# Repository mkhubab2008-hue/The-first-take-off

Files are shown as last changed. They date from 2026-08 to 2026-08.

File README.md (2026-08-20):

## 🎥 Demo
Watch The first take off :
## Overview
I wanted to make small esp32c3 based qaudcopter that I could control from my Phone. I first tried to use WiFi, but the WiFi chip on my ESP wouldnt seem to work. So, I switched to BLE. The drone uses an MPU6050 as its Gyroscope.
## How it works
The Gyroscope measures the rate of change of angles and the desired rates of roll pitch and yaw are sent over BLE from an android app that I made using MIT app maker. The micro-controller measures the difference between the desired rates and the current rates then uses a PID loop to calculate the motor input required at each motor to correct the rotation rates in each axis. The loop has a frequency of 250hz so fresh commands are sent to the motor every 4 milliseconds.
## Bill of Materials (BOM)

| Component | Description | Qty | Price (USD) | Link |
| :--- | :--- | :--- | :--- | :--- |
| **Microcontroller** | ESP32-C3 Super Mini Development Board | 1 | $2.21 | [AliExpress](https://www.aliexpress.com/w/wholesale-esp32-c3-super-mini.html) |
| **IMU Sensor** | GY-521 MPU-6050 6-DOF Accelerometer/Gyroscope | 1 | $1.59 | [AliExpress](https://www.aliexpress.com/w/wholesale-gy-521-mpu6050.html) |
| **Motors & Props** | 8520 Coreless Brushed DC Motors (CW/CCW) with Propellers | 4 | $5.81 | [AliExpress](https://www.aliexpress.com/w/wholesale-coreless-motor-8520-propeller.html) |
| **Motor Drivers** | SI2300 N-Channel MOSFETs (SOT-23 package) | 50 | $0.99 | [AliExpress](https://www.aliexpress.com/w/wholesale-si2300.html) |
| **Flyback Diodes** | 1N4148 Switching Diodes (SMD 1206) | 50 | $0.61 | [AliExpress](https://www.aliexpress.com/w/wholesale-switching-diode-1n4148.html) |
| **Gate Resistors** | 200Ω Resistors (PWM current limiting) | 100 | $0.99 | [AliExpress](https://www.aliexpress.com/w/wholesale-200-ohm-1-watt-resistor.html) |
| **Pull-down Resistors** | 10kΩ Resistors | 100 | $0.99 | [AliExpress](https://www.aliexpress.com/w/wholesale-10k-pull-up-resistor.html) |
| **Bulk Capacitor** | 470µF 16V/25V Electrolytic Capacitor (Main battery filtering) | 4 | $1.51 | [AliExpress](https://www.aliexpress.com/w/wholesale-470uf-capacitor.html) |
| **Capacitors** | 100µF & 10µF Assortment (Decoupling/Filtering) | 1 kit | $1.50 | [AliExpress](https://www.aliexpress.com/w/wholesale-smd-capacitor-assortment.html) |
| **Voltage Regulator** | XC6206P332MR 3.3V LDO Voltage Regulator (SOT-23) | 20 | $1.91 | [AliExpress](https://www.aliexpress.com/item/32811070407.html) |
| **Prototyping Board** | Double-sided Perfboard (2x8cm) | 10 | $1.20 | [AliExpress](https://www.aliexpress.com/w/wholesale-double-sided-perfboard.html) |
| **Wiring** | 30AWG Flexible Silicone Wire Kit | 1 kit | $3.50 | [AliExpress](https://www.aliexpress.com/w/wholesale-30awg-silicone-wire-kit.html) |
| **Battery** | 1S 3.7V 500mAh LiPo Battery | 1 | $7.00 | [AliExpress](https://www.aliexpress.com/item/1005003268560510.html) |
| **Airframe** | 3D Printed Frame Service (SLA/Resin) | 1 | $1.00 | [JLCPCB](https://jlcpcb.com/3d-printing) |
| **Total** | | | **$30.81** | |

## Wiring diagram
WhatsApp Image 2026-08-20 at 5 38 04 PM

## Programming
*Software required*:-
1) Arduino IDE
2) ESP32C3 libaries
3) MPU6050 library
4) BLE libraries

*Customizing the P, I and D gains*:-

In my opinion the only method for obtaining the right gains is just trial error; because everydrone, even if it foollows the same blueprint, will have a different COM and mass. The following guide can be quite helpful in determining the gains:-
WhatsApp Image 2026-08-20 at 11 23 37 AM
Furthermore, I think it is also prudent to add the ability to change the PID gains wirelessly as plugging the drone in repeatedly can be quite annoying. I did this by adding a BLE characteristic to wirelessly send the commands from my phone using nrf connect.

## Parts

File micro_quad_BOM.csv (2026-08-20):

Component | Description | Qty | Price (USD) | Link
Microcontroller | ESP32-C3 Super Mini Development Board | 1 | 2.21 | https://www.aliexpress.com/w/wholesale-esp32-c3-super-mini.html
IMU Sensor | GY-521 MPU-6050 6-DOF Accelerometer/Gyroscope | 1 | 1.59 | https://www.aliexpress.com/w/wholesale-gy-521-mpu6050.html
Motors & Props | 8520 Coreless Brushed DC Motors (CW/CCW) with Propellers | 4 | 5.81 | https://www.aliexpress.com/w/wholesale-coreless-motor-8520-propeller.html
Motor Drivers | SI2300 N-Channel MOSFETs (SOT-23 package) | 50 | 0.99 | https://www.aliexpress.com/w/wholesale-si2300.html
Flyback Diodes | 1N4148 Switching Diodes (SMD 1206) | 50 | 0.61 | https://www.aliexpress.com/w/wholesale-switching-diode-1n4148.html
Gate Resistors | 200Ω Resistors (PWM current limiting) | 100 | 0.99 | https://www.aliexpress.com/w/wholesale-200-ohm-1-watt-resistor.html
Pull-down Resistors | 10kΩ Resistors | 100 | 0.99 | https://www.aliexpress.com/w/wholesale-10k-pull-up-resistor.html
Bulk Capacitor | 470µF 16V/25V Electrolytic Capacitor (Main battery filtering) | 4 | 1.51 | https://www.aliexpress.com/w/wholesale-470uf-capacitor.html
Capacitors | 100µF & 10µF Assortment (Decoupling/Filtering) | 1 kit | 1.50 | https://www.aliexpress.com/w/wholesale-smd-capacitor-assortment.html
Voltage Regulator | XC6206P332MR 3.3V LDO Voltage Regulator (SOT-23) | 20 | 1.91 | https://www.aliexpress.com/item/32811070407.html
Prototyping Board | Double-sided Perfboard (2x8cm) | 10 | 1.20 | https://www.aliexpress.com/w/wholesale-double-sided-perfboard.html
Wiring | 30AWG Flexible Silicone Wire Kit | 1 kit | 3.50 | https://www.aliexpress.com/w/wholesale-30awg-silicone-wire-kit.html
Battery | 1S 3.7V 500mAh LiPo Battery | 1 | 7.00 | https://www.aliexpress.com/item/1005003268560510.html
Airframe | 3D Printed Frame Service (SLA/Resin) | 1 | 1.00 | https://jlcpcb.com/3d-printing
Total |  |  | 30.81

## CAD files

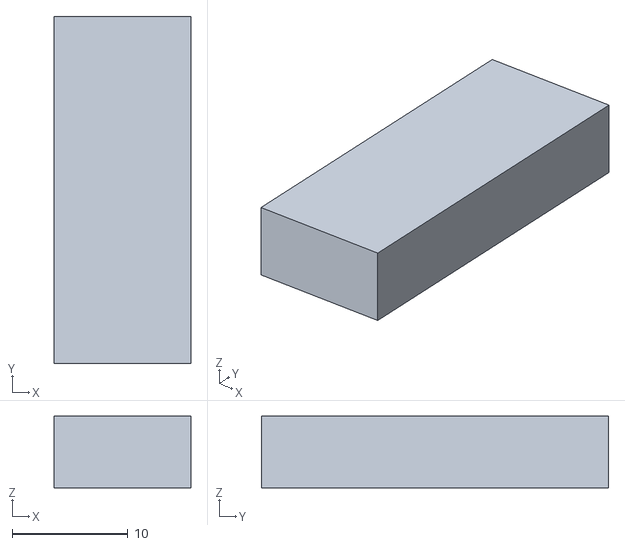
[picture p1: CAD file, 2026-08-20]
Part Studio 1 (5).stl
11.8 x 30.0 x 6.21

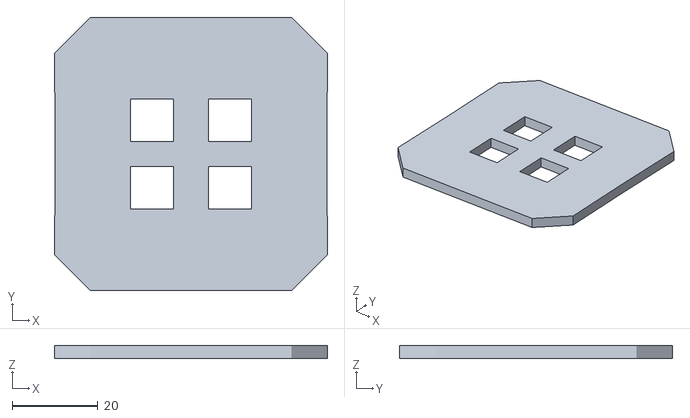
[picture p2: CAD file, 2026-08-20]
Part Studio 1 (6).stl
63.7 x 63.7 x 3.00

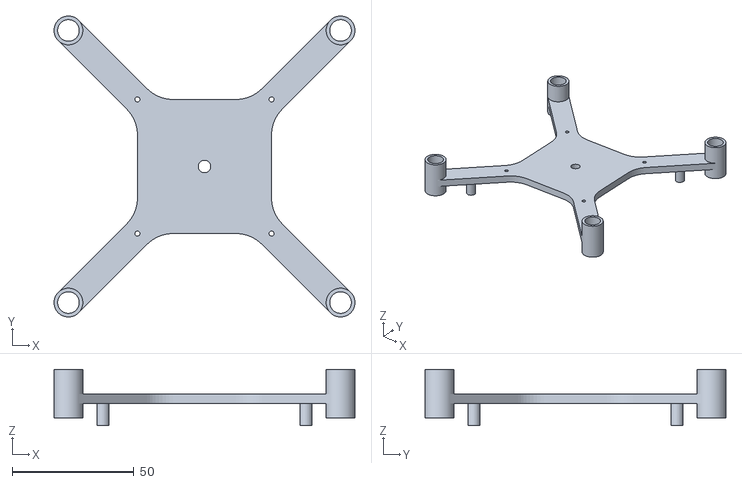
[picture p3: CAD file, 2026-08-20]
Part Studio 1 (7).stl
123.4 x 123.4 x 23.0

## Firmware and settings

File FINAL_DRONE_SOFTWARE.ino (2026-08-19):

#include <BLEDevice.h>//includes the right esp32 based BLE libraries
#include <BLEutils.h>
#include <BLEServer.h>
#include <Wire.h>
float PitchRate;
float YawRate;
float RollRate;
float Rateroll;
float Ratepitch;
float Rateyaw;
float sum1 = 0;
float sum2 = 0;
float sum3= 0;
int MOTOR1 = 0;
int MOTOR2 = 0;
int MOTOR3 = 0;
int MOTOR4 = 0;
uint8_t throttle_value;
uint8_t Yaw_value;
uint8_t Pitch_value;
uint32_t LoopTimer;
float DesiredRateRoll, DesiredRatePitch, DesiredRateYaw;
float ErrorRateRoll, ErrorRatePitch, ErrorRateYaw;
float InputRoll, InputThrottle, InputPitch, InputYaw;
float PrevErrorRateRoll, PrevErrorRatePitch, PrevErrorRateYaw;
float PrevItermRateRoll, PrevItermRatePitch, PrevItermRateYaw;
float PIDReturn[]={0, 0, 0};
float PRateRoll=0.6; 
float PRatePitch = PRateRoll;
float PRateYaw=2;
float IRateRoll=3.5;
float IRatePitch=IRateRoll;
float IRateYaw=12;
float DRateRoll=0.03;
float DRatePitch=DRateRoll;
float DRateYaw=0;
float MotorInput1, MotorInput2, MotorInput3, MotorInput4;
void pid_equation (float Error, float P, float I, float D, float PrevError, float PrevIterm){
  float Pterm = P*Error;
  float Iterm = PrevIterm + I*(Error+PrevError)*0.004/2;
  if (Iterm>400)Iterm=400;
  else if (Iterm<-400)Iterm=-400;
  float Dterm=D*(Error-PrevError)/0.004;
  float PIDOutput=Pterm+Iterm+Dterm;
  if (PIDOutput>400)PIDOutput=-400;
  else if (PIDOutput<-400)PIDOutput=-400;  
  PIDReturn[0]=PIDOutput;
  PIDReturn[1]=Error;
  PIDReturn[2]=Iterm; 
}
void reset_pid(){
  PrevErrorRateRoll=0;PrevErrorRatePitch=0;PrevErrorRateYaw=0;
  PrevItermRateRoll=0;PrevItermRatePitch=0;PrevItermRateYaw=0;
}
void gyro_signal () {
  Wire.beginTransmission(0x68);
  Wire.write(0x43);
  Wire.endTransmission(false);
    Wire.requestFrom(0x68, 6);
  if (Wire.available()>=6){
    int16_t GyroX = Wire.read()<<8|Wire.read();
    int16_t GyroY = Wire.read()<<8|Wire.read();
    int16_t GyroZ = Wire.read()<<8|Wire.read();
    Rateroll =(float)GyroX/65.5;
    Ratepitch =(float)GyroY/65.5;
    Rateyaw =(float)GyroZ/65.5;
    
  }
  
}
#define ServiceUUID "a4d18b1d-590f-4cfe-b569-6d951816dc49" //defines a variable named ServerUUID which stores the UUID crazy right
#define CharacteristicUUID "13cc3dac-71c9-4f9b-b550-78e84716ed42"
#define Characteristic1UUID "30140440-74a7-4661-91b5-56baa79e427b"//defines a variable named characteristicUUID which stores the UUID of the characteristic crazy right
#define Characteristic2UUID "c8b65fc7-0c30-4b3f-a4d8-e2bc6e7a5af9"
#define Characteristic3UUID "d8e8225b-9257-49f0-af1d-4cbe1a65b0d5"
#define Characteristic4UUID "5ad3fe2c-f2df-4fed-9440-625eef816318"

bool deviceConnected = false;//keeps the initial state of device connected false
class Gaurd_doggy: public BLEServerCallbacks{//Writes a class by the name of Gaurd_doggy which inherits from the public class BLEServerCallback
void onConnect (BLEServer *pserver){//This is a function from the BLE libraries which detects when the phone connects to the esp
 deviceConnected = true;
  Serial.println("Phone connected!");

}
void onDisconnect (BLEServer *pserver ){//This is a fucntion from the BLE libaries which detects when the phone disconnects to the esp 
  deviceConnected = false;
  throttle_value=0;
  Serial.println("Phone disconnected, Restarting advertising again...");
  BLEDevice::startAdvertising();//Starts sending radio wavees once the phone disconnects
}
;};

class PIDCallBacks: public BLECharacteristicCallbacks {
  void onwrite(BLECharacteristic *pCharacteristic){
    String rxvalue = pCharacteristic->getValue();
  if (rxvalue.length() >0){
    char axis;
    float p_gain, i_gain, d_gain;
    int parsed = sscanf(rxvalue.c_str(), "%c,%f,%f,%f", &axis, &p_gain, &i_gain, &d_gain);
  
if (parsed == 4){
  if(axis == 'R' ){
    PRateRoll = p_gain;
    IRateRoll = i_gain;
    DRateRoll = d_gain;
    Serial.println("Roll PID Updated!");
  }
  else if(axis == 'P'){
    PRatePitch = p_gain;
    IRatePitch = i_gain;
    DRatePitch = d_gain;
    Serial.println("Pitch PID Updated!");
  }
  else if(axis == 'Y'){
    PRateYaw = p_gain;
    IRateYaw= i_gain;
    DRateYaw= d_gain;
    Serial.println("Yaw PID Updated!");
  }
}
 }
  }
};
class ThrottleCallBacks: public BLECharacteristicCallbacks{
  void onWrite(BLECharacteristic *pCharacteristic1) {
    String rxvalue1 = pCharacteristic1->getValue();
    
    // Check if we received at least 1 byte
    if (rxvalue1.length() > 0){ 
      // Read exactly the first byte 
      throttle_value = (uint8_t)rxvalue1[0]; 
      
      Serial.print("Throttle Received: ");
      Serial.println(throttle_value);
    }
  }
};

class PitchCallBacks: public BLECharacteristicCallbacks{
  void onWrite(BLECharacteristic *pCharacteristic2){
    String rxvalue2 = pCharacteristic2->getValue();
    if (rxvalue2.length()>0){    
    uint8_t raw_pitch = (uint8_t)rxvalue2[0] ;
    DesiredRatePitch = ((float)raw_pitch - 127.0)/4.0;
    Serial.print("Rate Pitch Recieved:");
    Serial.print(DesiredRatePitch);
    }

  }
};

class RollCallBacks: public BLECharacteristicCallbacks{
  void onWrite (BLECharacteristic *pCharacteristic3){
    String rxvalue3 = pCharacteristic3->getValue();
    if (rxvalue3.length()>0){    
    uint8_t value3 = (uint8_t)rxvalue3[0];
    DesiredRateRoll = ((float)value3-127.0)/4.0;
    Serial.print("Rate Roll Recieved:");
    Serial.println(DesiredRateRoll);
  }}

};
class YawCallBacks: public BLECharacteristicCallbacks{
  void onWrite (BLECharacteristic *pCharacteristic4){
    String rxvalue4 = pCharacteristic4->getValue();
  if (rxvalue4.length()>0){
    uint8_t value4 = (uint8_t)rxvalue4[0];
    DesiredRateYaw = ((float)value4-127.0)/4.0;
    Serial.print("Rate Yaw Recieved:");
    Serial.print(DesiredRateYaw);
  }
  }
};

void setup() {
  Serial.begin(115200);//start serial comms
Wire.setClock(400000);
Wire.begin(2,1);
  pinMode(MOTOR1, OUTPUT);
  pinMode(MOTOR2, OUTPUT);
  pinMode(MOTOR3, OUTPUT);
  pinMode(MOTOR4, OUTPUT);
  analogWrite(5, 0);
  analogWrite(MOTOR2, 0);
  analogWrite(MOTOR3, 0);
  Wire.beginTransmission(0x68);
  Wire.write(0x1A);
  Wire.write(0x05);
  Wire.endTransmission(false);
  Wire.beginTransmission(0x68);
  Wire.write(0x1B);
  Wire.write(0x08);
  Wire.endTransmission();
  Wire.beginTransmission(0x68);
Wire.write(0x6B);
Wire.write(0x00);
Wire.endTransmission();

int i=0;
for (i=0; i<= 2000;i++){
  gyro_signal();
  sum1 += Rateroll;
  sum2 += Ratepitch;
  sum3 += Rateyaw;
}
BLEDevice::init("Drone");//Turns on the bluetooth chip on the esp32
BLEServer *pServer = BLEDevice::createServer();//calls the create server function and stores its address in the variable p server
pServer->setCallbacks(new Gaurd_doggy());
BLEService *pService = pServer->createService(ServiceUUID);//Creates a service with the server uuid of our uuid and uses p server address 
BLECharacteristic *pCharacteristic1 = pService->createCharacteristic(Characteristic1UUID, //This creates a characteristic inside of the service cabinet and stores the address of the characteristic inside of the variable p characteristic
                                                                    BLECharacteristic::PROPERTY_WRITE |//Since the function takes only one argument for permission the| combines two arguments which allow reading writing data
                                                                    BLECharacteristic::PROPERTY_READ);
pCharacteristic1->setCallbacks(new ThrottleCallBacks());
BLECharacteristic *pCharacteristic2 = pService->createCharacteristic(Characteristic2UUID, BLECharacteristic::PROPERTY_WRITE | BLECharacteristic::PROPERTY_READ);
pCharacteristic2->setCallbacks(new PitchCallBacks());
BLECharacteristic *pCharacteristic3 = pService->createCharacteristic(Characteristic3UUID, BLECharacteristic::PROPERTY_WRITE | BLECharacteristic::PROPERTY_READ);
pCharacteristic3->setCallbacks(new RollCallBacks());
BLECharacteristic *pCharacteristic4 = pService->createCharacteristic(Characteristic4UUID, BLECharacteristic::PROPERTY_WRITE | BLECharacteristic::PROPERTY_READ);
pCharacteristic4->setCallbacks(new YawCallBacks());
BLECharacteristic *pCharacteristic = pService->createCharacteristic(CharacteristicUUID, BLECharacteristic::PROPERTY_WRITE | BLECharacteristic::PROPERTY_READ);
pService->start();//starts the thing
BLEAdvertising *pAdvertising = BLEDevice::getAdvertising(); //Creates a variable pAdvertising and stores the advertising modules address in there
pAdvertising->addServiceUUID(ServiceUUID); //starts advertising at that address with the specfic UUID
pAdvertising->setScanResponse(true); 
BLEDevice::startAdvertising();
LoopTimer=micros();

}

void loop() {
  gyro_signal();
  RollRate = Rateroll - (sum1/2000);
  PitchRate = Ratepitch - (sum2/2000);
  YawRate = Rateyaw - (sum3/2000);
  ErrorRateRoll=DesiredRateRoll-RollRate;
  ErrorRatePitch=DesiredRatePitch-PitchRate;
  ErrorRateYaw=DesiredRateYaw-YawRate;
  pid_equation(ErrorRateRoll, PRateRoll, IRateRoll, DRateRoll, PrevErrorRateRoll, PrevItermRateRoll);
  InputRoll=PIDReturn[0];
  PrevErrorRateRoll=PIDReturn[1];
  PrevItermRateRoll=PIDReturn[2];
  pid_equation(ErrorRatePitch, PRatePitch, IRatePitch, DRatePitch, PrevErrorRatePitch, PrevItermRatePitch);
  InputPitch=PIDReturn[0];
  PrevErrorRatePitch=PIDReturn[1];
  PrevItermRatePitch=PIDReturn[2];
  pid_equation(ErrorRateYaw, PRateYaw, IRateYaw, DRateYaw, PrevErrorRateYaw, PrevItermRateYaw);
  InputYaw=PIDReturn[0];
  PrevErrorRateYaw=PIDReturn[1];
  PrevItermRateYaw=PIDReturn[2];
  InputThrottle=throttle_value*4.0;
  MotorInput1=InputThrottle-InputRoll-InputPitch-InputYaw;
  MotorInput2=InputThrottle-InputRoll+InputPitch+InputYaw;
  MotorInput3=InputThrottle+InputRoll+InputPitch-InputYaw;
  MotorInput4=InputThrottle+InputRoll-InputPitch+InputYaw;
  MotorInput1=constrain(MotorInput1, 0, 1023);
  MotorInput2=constrain(MotorInput2, 0, 1023);
  MotorInput3=constrain(MotorInput3, 0, 1023);
  MotorInput4=constrain(MotorInput4, 0, 1023);
if(throttle_value<15){
  MotorInput1=0;
  MotorInput2=0;
  MotorInput3=0;
  MotorInput4=0;

}
analogWrite(MOTOR1, MotorInput1);
analogWrite(MOTOR2, MotorInput2);
analogWrite(MOTOR3, MotorInput3);
analogWrite(MOTOR4, MotorInput4);
while(micros()-LoopTimer<4000);
LoopTimer=micros();
}

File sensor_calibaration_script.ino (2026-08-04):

#include <Wire.h>
float rateroll;
float ratepitch;
float rateyaw;
float sum1 = 0;
float sum2 = 0;
float sum3= 0;
void gyro_signals(){

  Wire.beginTransmission(0x68);
  Wire.write(0x43);
  Wire.endTransmission(false);
  Wire.requestFrom(0x68,6);//Ask the mpu6050 for 6 bits to read the 6 registers 43-48
  if (Wire.available() >= 6) {
  int16_t GyroX = Wire.read()<<8|Wire.read();// add the values from register 43 and 44 and then store them in the variable GyroX
  int16_t GyroY = Wire.read()<<8|Wire.read();
  int16_t GyroZ = Wire.read()<<8|Wire.read();
  rateroll = (float)GyroY/65.5;
  ratepitch = (float)GyroX/65.5;
  rateyaw = (float)(GyroZ/65.5);
  }
}

void setup(){
  Wire.beginTransmission(0x68);//Start talking to mpu6050 with the address 0x68
  Wire.write(0x1A);//acceess the register with low pass filter which has an adress 0x1A
  Wire.write(0x05);//This is the value for the low pass filter which has bancwith of 10hz
  Wire.endTransmission();
  Wire.beginTransmission(0x68);
  Wire.write(0x1B);//Access the register that has the senstivity settings
  Wire.write(0x8);//Select the senstivity setting of 65.5 lsb per degrees which corrosponds to a hexadecimal address of 8
  Wire.endTransmission();
Serial.begin(2000000);
Wire.setClock(400000);
Wire.begin(2, 1);
delay(300);
Wire.beginTransmission(0x68);
Wire.write(0x6B);//Access the register with the power management stuff
Wire.write(0x00);//turn on the mpu6050
Wire.endTransmission();//stop communication with the mpu 6050
int i;
for (i=0; i<2300; i++){
  gyro_signals();
  sum1 += rateroll;
  sum2 += ratepitch;
  sum3 += rateyaw;
}
}
void loop(){
gyro_signals();
float rollerror = sum1/2300;
float pitcherror = sum2/2300;
float yawerror = sum3/2300;
float Rateroll = rateroll - rollerror;
float Ratepitch = ratepitch - pitcherror;
float Rateyaw = rateyaw - yawerror;
Serial.print(" Rollrate/° = ");
Serial.print(Rateroll);
Serial.print(" Pitchrate/° = ");
Serial.print(Ratepitch);
Serial.print(" Yawrate/° = ");
Serial.println(Rateyaw);
delay(50);
}
